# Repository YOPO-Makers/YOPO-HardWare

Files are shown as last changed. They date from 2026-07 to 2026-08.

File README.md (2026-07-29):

# 无人机硬件清单

| 硬件名 | 数量 | 功能简介 |
|---|---:|---|
| 边缘计算机套件：Nvidia Orin NX | 1 | [查看详细介绍](#detail-orin-nx) |
| RGB-D 深度相机：RealSense D455 | 1 | [查看详细介绍](#detail-d455) |
| 飞控：NxtPX4 | 1 | [查看详细介绍](#detail-nxtpx4) |
| 电调：45A（当前使用，型号待补充） | 1 | [查看详细介绍](#detail-esc-45a) |
| 电机：OddityRC 2006 2150KV 四个装 | 1 | [查看详细介绍](#detail-motor) |
| 螺旋桨：GEMFAN D90s-3 四个装 | 1 | [查看详细介绍](#detail-propeller) |
| 电池：1400mAh 6S | 1 | [查看详细介绍](#detail-battery) |
| 电池防撞护垫 | 1 | [查看详细介绍](#detail-battery-protector) |
| 电池绑带：凯夫拉 20×280mm 防滑扎带 | 1 | [查看详细介绍](#detail-battery-strap) |
| 桨叶保护罩：OddityRC XI35 Pro | 1 | [查看详细介绍](#detail-prop-guard) |
| 接收器：瑞速 | 1 | [查看详细介绍](#detail-receiver) |
| 遥控器 | 1 | [查看详细介绍](#detail-transmitter) |
| 电源接口：XT60 E1-M | 1 | [查看详细介绍](#detail-xt60-em) |
| XT30 对（10 个装） | 1 | [查看详细介绍](#detail-xt30) |
| 计算机电源线：18 AWG 红色，1m 长 | 4 | [查看详细介绍](#detail-power-red) |
| 计算机电源线：18 AWG 黑色，1m 长 | 4 | [查看详细介绍](#detail-power-black) |
| 硅胶线：28 AWG 绿色，0.08平方，5m 长 | 1 | [查看详细介绍](#detail-wire-28awg-green) |
| 硅胶线：28 AWG 白色，0.08平方，5m 长 | 1 | [查看详细介绍](#detail-wire-28awg-white) |
| 硅胶线：28 AWG 红色，0.08平方，5m 长 | 1 | [查看详细介绍](#detail-wire-28awg-red) |
| 硅胶线：28 AWG 黑色，0.08平方，5m 长 | 1 | [查看详细介绍](#detail-wire-28awg-black) |
| 相机 Type-C 线 | 1 | [查看详细介绍](#detail-camera-cable) |
| Type-C 调试母座（机架下板安装位） | 1 | [查看详细介绍](#detail-debug-female) |
| Type-C 调试公头 | 1 | [查看详细介绍](#detail-debug-male) |
| DC-DC 降压模块，输出 12V 5A | 1 | [查看详细介绍](#detail-dcdc) |
| 铝合金支柱：M3×12mm | 7颗 | [查看详细介绍](#detail-standoff) |
| 内六角沉头螺丝M3×10mm | 7颗 | [查看详细介绍](#detail-screw) |
| 尼龙螺丝：M2×20mm，白色 | 4颗 | [查看详细介绍](#detail-nylon-screw-m2-20) |
| 尼龙螺母：M2，白色 | 8颗 | [查看详细介绍](#detail-nylon-nut-m2) |
| 内六角沉头螺丝：M3×20mm | 6颗 | [查看详细介绍](#detail-countersunk-m3-20) |
| 内六角沉头螺丝：M2.5×10mm | 2颗 | [查看详细介绍](#detail-countersunk-m2-5-10) |
| 内六角沉头螺丝：M2.5×7mm | 4颗 | [查看详细介绍](#detail-countersunk-m2-5-7) |
| 内六角平头螺丝：M4×8mm | 2颗 | [查看详细介绍](#detail-screw-m4-8) |
| 平头螺丝：M3×12mm | 2颗 | [查看详细介绍](#detail-flat-screw-m3-12) |
| 平头螺丝：M3×14mm | 1颗 | [查看详细介绍](#detail-flat-screw-m3-14) |
| 防松螺母：M3 | 2颗 | [查看详细介绍](#detail-locknut-m3) |
| 缓冲泡棉（用于电池，2m） | 1 | [查看详细介绍](#detail-foam) |
| 3M 背胶魔术贴：黑色，2cm 宽，3m 勾面 + 3m 毛面 | 1 | [查看详细介绍](#detail-velcro) |
| 尼龙扎带：白色，25cm，中粗，100条装 | 1 | [查看详细介绍](#detail-zip-tie) |
| 固态电容：680µF（更紧凑） | 1 | [查看详细介绍](#detail-capacitor) |
| 热缩管：黑色，圆直径 4mm，按 2m 散卖 | 1 | [查看详细介绍](#detail-heatshrink-4mm) |
| 热缩管：黑色，圆直径 2mm，按 2m 散卖 | 1 | [查看详细介绍](#detail-heatshrink-2mm) |
| 热缩管：黑色，圆直径 25mm | 1 | [查看详细介绍](#detail-heatshrink-25mm) |
| 3K 东丽碳纤维板定制加工 | 1 | [查看详细介绍](#detail-carbon-fiber) |
| PETG 3D 打印定制件 | 6 | [查看详细介绍](#detail-petg-print) |
| BB 响 | 1 | [查看详细介绍](#detail-buzzer) |

## 硬件详细介绍

### 边缘计算机套件：Nvidia Orin NX

**具体型号：**

Allspark 2-Orin NX 16G+128G SSD+wifi版本 100TOPS

**功能简介：**

Nvidia Orin NX 是无人机上的机载边缘计算平台。

**参考图片：**

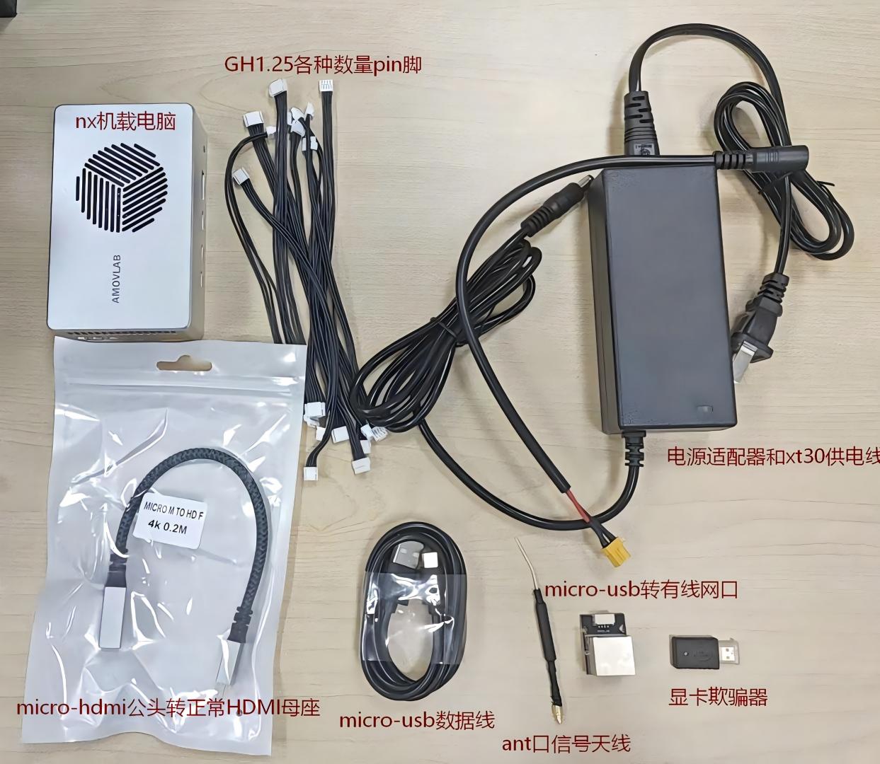
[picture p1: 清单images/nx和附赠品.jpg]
Nvidia Orin NX 及附赠品


**淘宝购买链接：**

[点击查看机载电脑商品（SKU：5396774401953）](https://item.taobao.com/item.htm?id=705748339987&skuId=5396774401953)

[返回硬件清单](#hardware-list)

### RGB-D 深度相机：RealSense D455

**功能简介：** 用于采集彩色图像和深度信息，为目标识别、测距、避障和定位提供视觉数据。

**参考图片：**

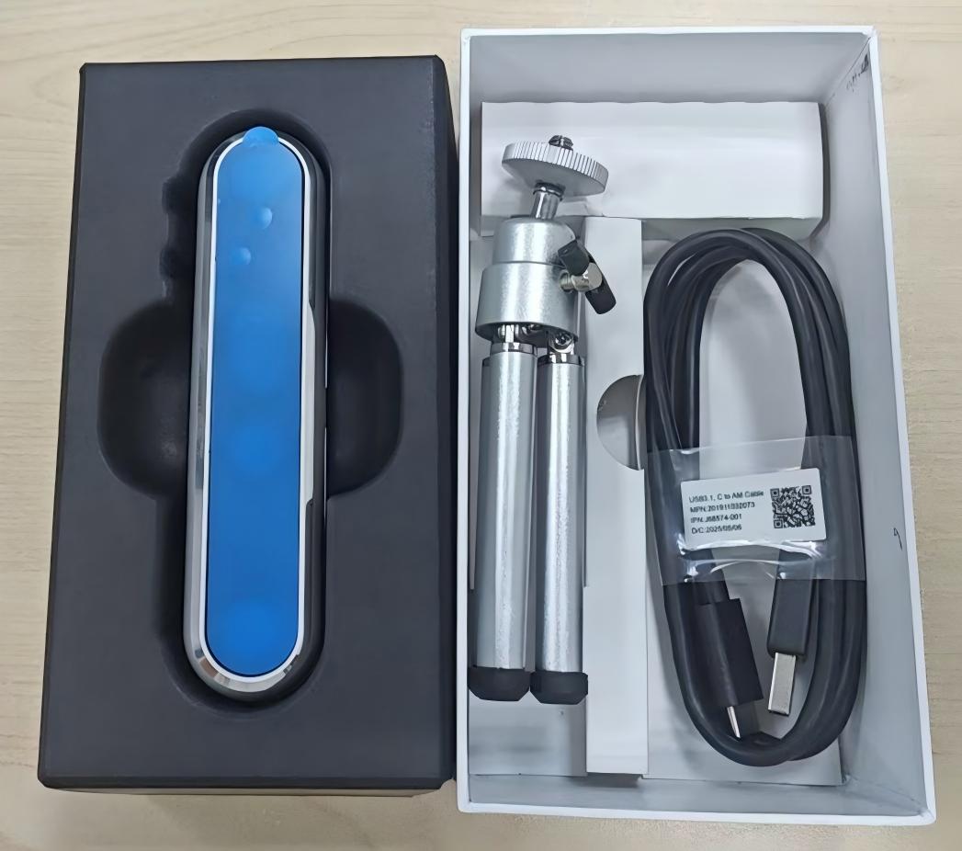
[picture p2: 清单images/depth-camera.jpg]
深度相机 示例图片


**淘宝购买链接：**

[点击查看深度相机商品（SKU：4457168412136）](https://item.taobao.com/item.htm?id=559722720199&skuId=4457168412136)

[返回硬件清单](#hardware-list)

### 飞控：NxtPX4

**功能简介：** 负责姿态估计、飞行控制、电机输出以及与遥控器、接收器和机载计算机的通信。

**淘宝购买链接：**

[点击查看飞控商品（SKU：6048678263114）](https://item.taobao.com/item.htm?id=955672079963&skuId=6048678263114)

**参考图片：**

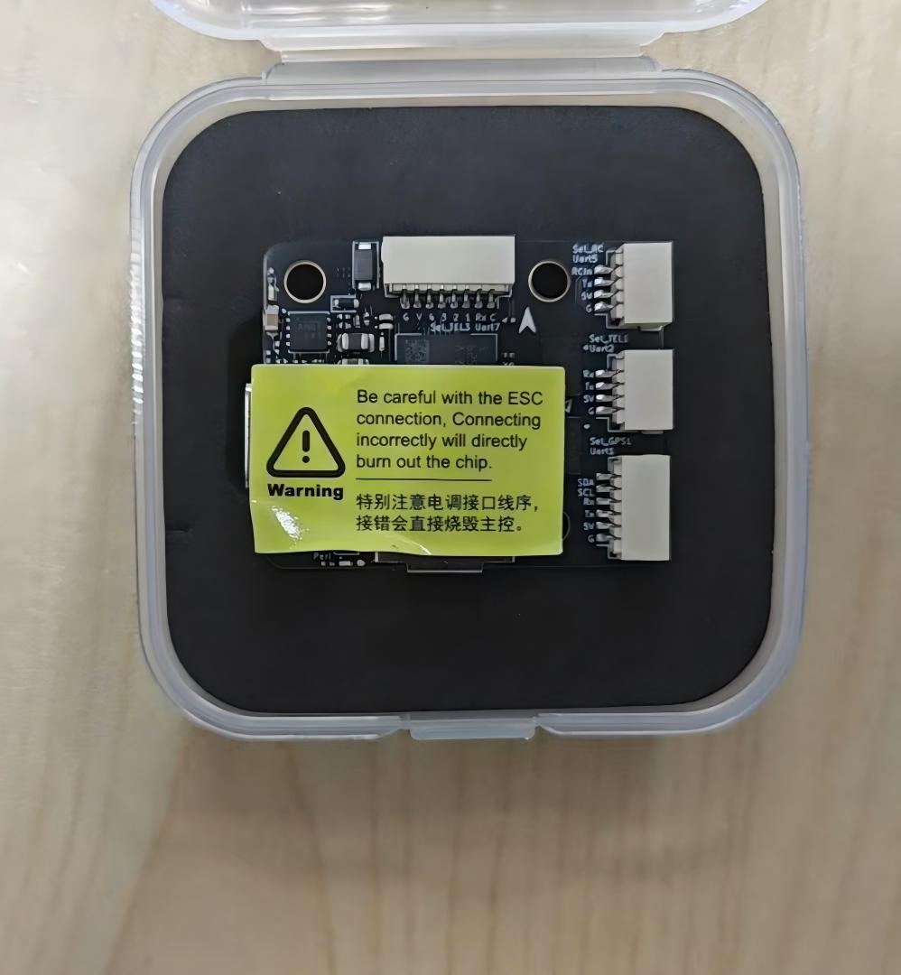
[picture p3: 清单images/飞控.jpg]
飞控 NxtPX4


[返回硬件清单](#hardware-list)

### 电调：45A（当前使用，型号待补充）

**功能简介：** 将 6S 电池的直流电转换为三相驱动信号，控制四个无刷电机的转速和方向。

**状态：** 当前方案使用尺寸匹配的 45A 电调，具体品牌、型号和淘宝购买链接待补充。

**参考图片：**

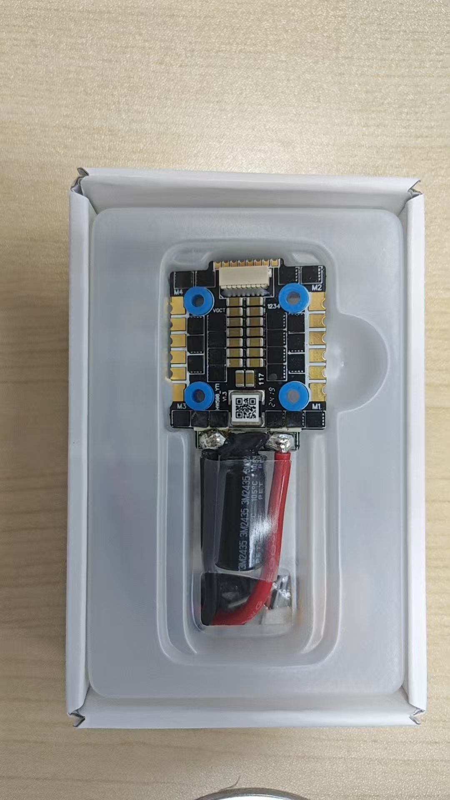
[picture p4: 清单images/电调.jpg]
45A 电调


[返回硬件清单](#hardware-list)

### 电机：OddityRC 2006 2150KV 四个装

**功能简介：** 为螺旋桨提供旋转动力，是无人机动力系统的核心执行部件；本款 2006 2150KV 电机适配三孔螺旋桨安装方式。

**参考图片：**

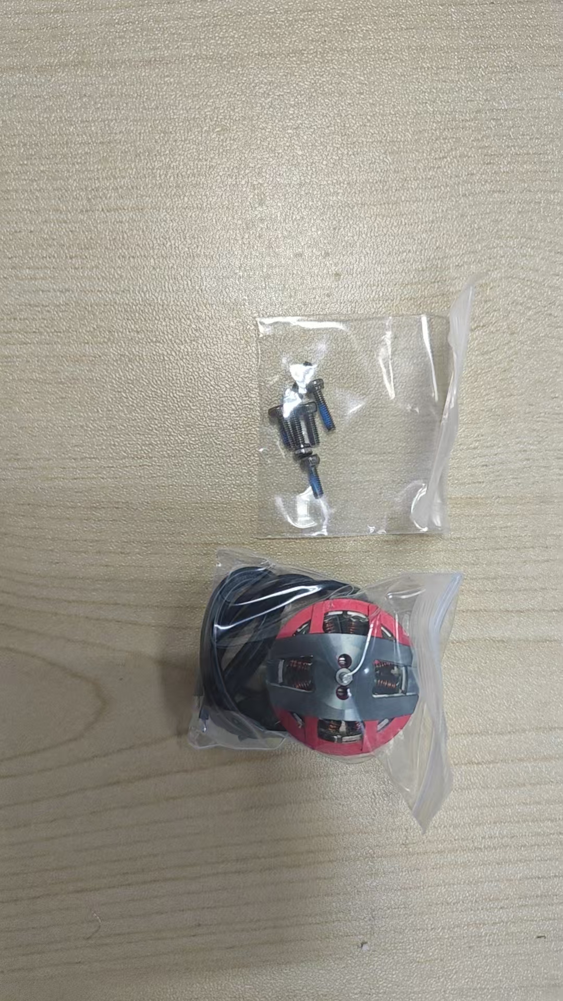
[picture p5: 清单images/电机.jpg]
无刷电机


**历史购买链接：**

[查看原 OddityRC 2006 电机商品（已售罄）](https://item.taobao.com/item.htm?id=793989229752&sku_properties=1627207%3A32402027293)

> 该商品已经卖完，此链接仅用于记录当初购买的型号，不代表当前可购买。

[返回硬件清单](#hardware-list)

### 螺旋桨：GEMFAN D90s-3 四个装

**功能简介：** 将电机的旋转动力转换为升力和推力，是无人机产生飞行动力的部件。

**参考图片：**

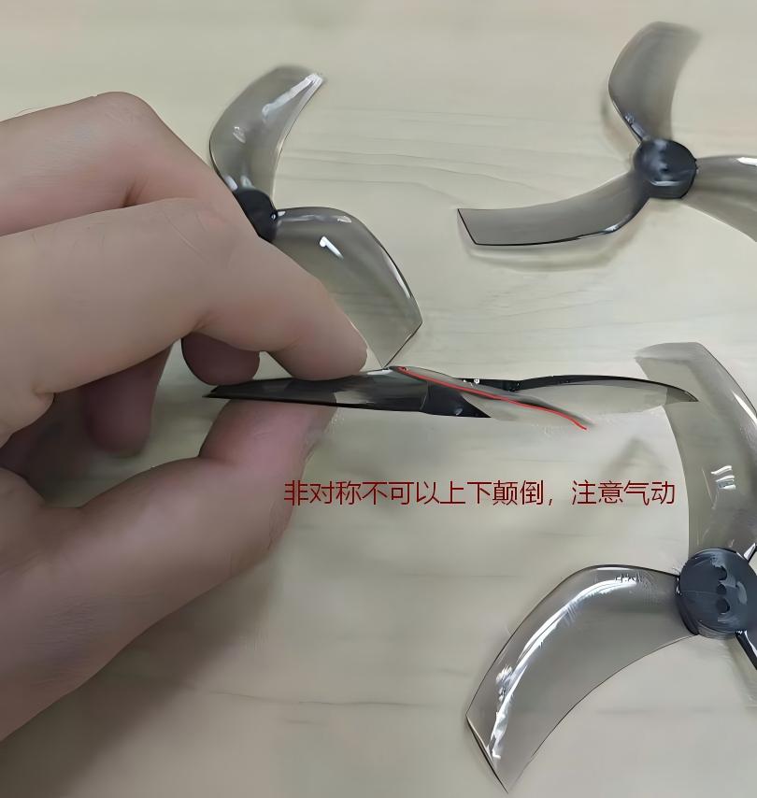
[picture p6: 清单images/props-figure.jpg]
三孔螺旋桨示意图


**购买链接：**

[点击查看三孔螺旋桨商品（SKU：5675481147990）](https://item.taobao.com/item.htm?id=811737228893&skuId=5675481147990)

> 本电机为中间光轴、两侧带安装孔，因此选用三孔螺旋桨；如果电机只有中间单轴、没有两侧安装孔，应改用单孔螺旋桨。

[返回硬件清单](#hardware-list)

### 电池：1400mAh 6S

**功能简介：** 为电机、电调和机载电子设备提供 6S 直流电源，是无人机的主要动力能源。

**参考图片：**

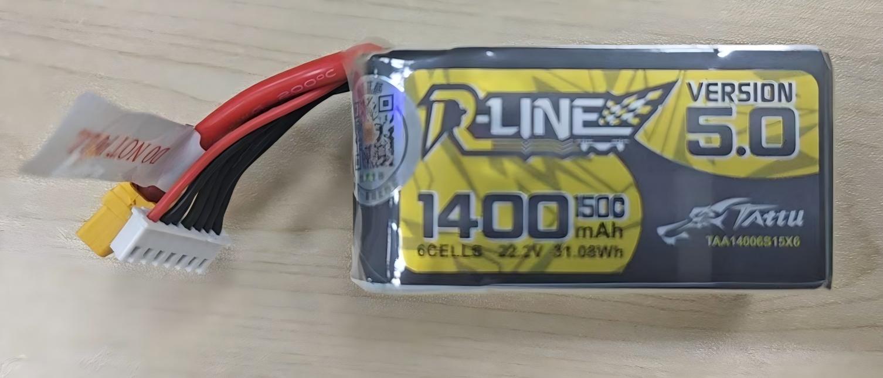
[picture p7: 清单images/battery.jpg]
1400mAh 6S 电池


**淘宝购买链接：**

[点击查看淘宝商品（SKU：5449796720472）](https://item.taobao.com/item.htm?id=677691756050&skuId=5449796720472)

**参考购买价：** 166.50 元

[返回硬件清单](#hardware-list)

### 电池防撞护垫

**功能简介：** 用于缓冲电池与机架或周边结构的碰撞，减少电池外壳磨损和飞行振动。

**参考图片：**

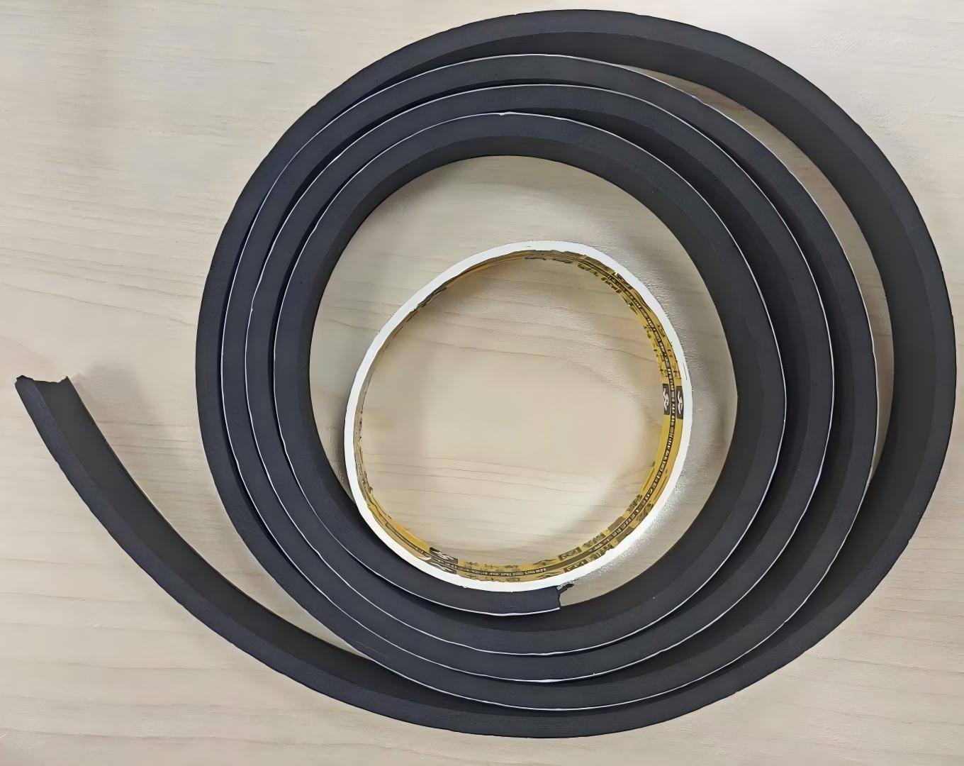
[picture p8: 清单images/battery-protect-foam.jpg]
电池防撞护垫


**淘宝购买链接：**

[点击查看电池防撞商品（SKU：6010611489926）](https://item.taobao.com/item.htm?id=1008514063717&skuId=6010611489926)

[返回硬件清单](#hardware-list)

### 电池绑带：凯夫拉 20×280mm 防滑扎带

**功能简介：** 用于固定 5 寸及 7 寸穿越机电池，防止电池在飞行过程中移动或脱落。

**规格：** 凯夫拉材质，20×280mm，防滑款，数量 4。

**淘宝购买链接：**

[点击查看商品（商品 ID：752606680898）](https://item.taobao.com/item.htm?id=752606680898)

**参考图片：**

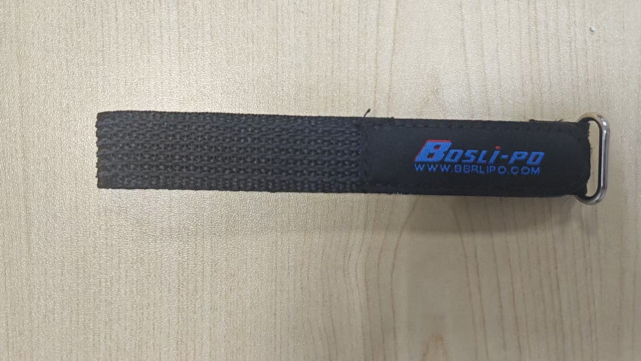
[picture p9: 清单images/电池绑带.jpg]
电池绑带


[返回硬件清单](#hardware-list)

### 桨叶保护罩：OddityRC XI35 Pro

**功能简介：** 用于隔离螺旋桨与外部障碍物，降低碰撞时桨叶和人员受伤的风险。

**参考图片：**

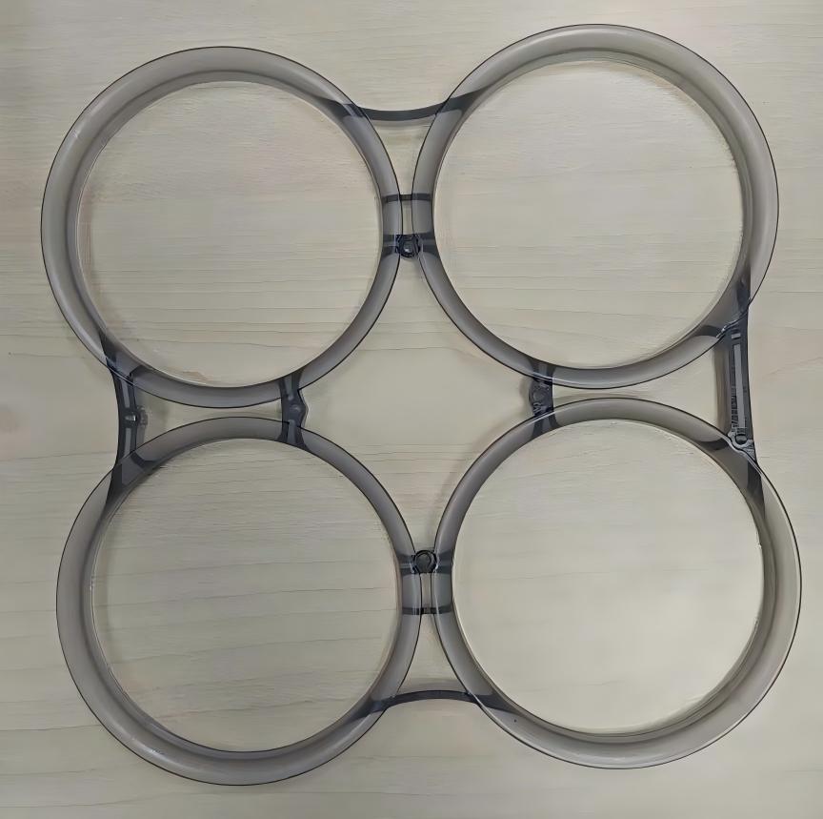
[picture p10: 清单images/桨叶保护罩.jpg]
桨叶保护罩


**淘宝购买链接：**

[点击查看涵道保护圈商品（SKU：5815214173777）](https://item.taobao.com/item.htm?id=930567172186&skuId=5815214173777)

[返回硬件清单](#hardware-list)

### 接收器：瑞速

**功能简介：** 接收遥控器发出的控制指令，并传递给飞控执行油门、姿态和模式控制。

**参考图片：**

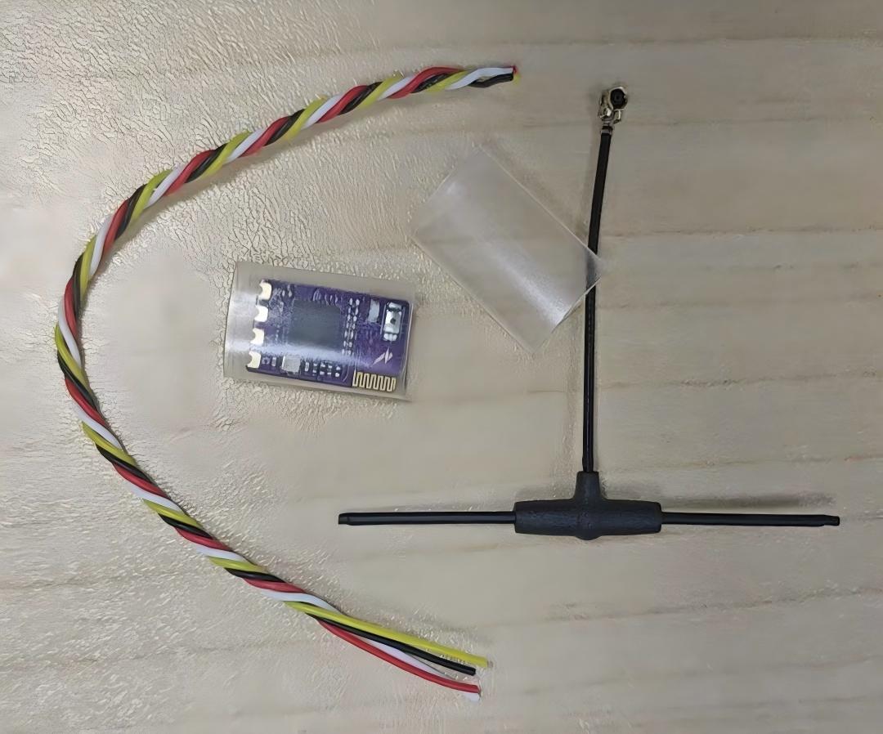
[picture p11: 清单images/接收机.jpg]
接收机


**淘宝购买链接：**

[点击查看接收机商品（SKU：6059615692701）](https://item.taobao.com/item.htm?id=1039148819082&skuId=6059615692701)

[返回硬件清单](#hardware-list)

### 遥控器

**功能简介：** 用于向接收器发送飞行控制、模式切换和安全解锁指令。

**参考图片：**

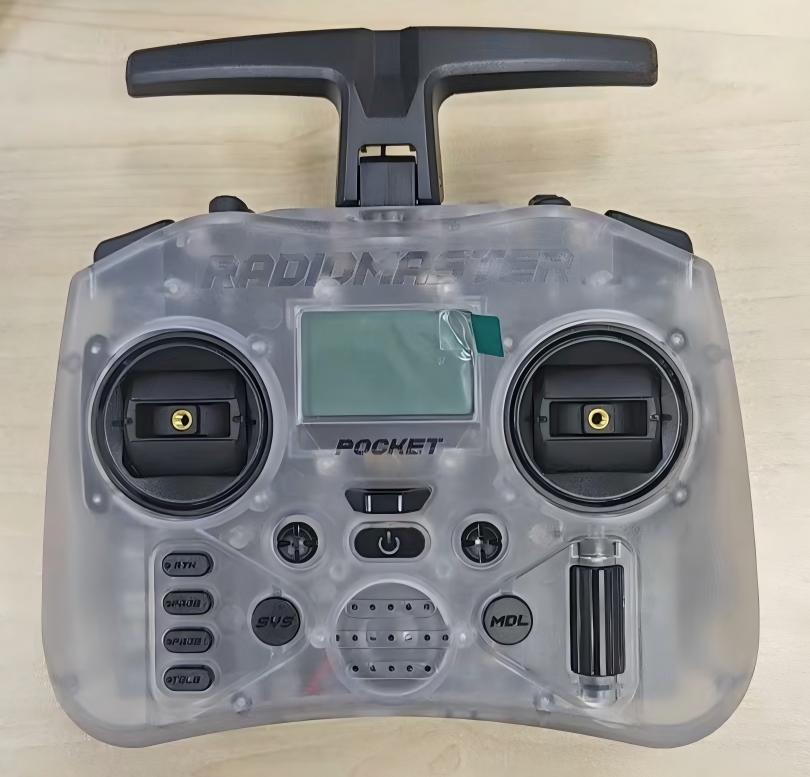
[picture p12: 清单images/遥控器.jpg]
遥控器


**淘宝购买链接：**

[点击查看遥控器商品（SKU：5690791865430）](https://item.taobao.com/item.htm?id=789612406107&skuId=5690791865430)

[返回硬件清单](#hardware-list)

### 电源接口：XT60 E1-M

**功能简介：** 提供电池与无人机电源系统之间的大电流可插拔连接。

**参考图片：**

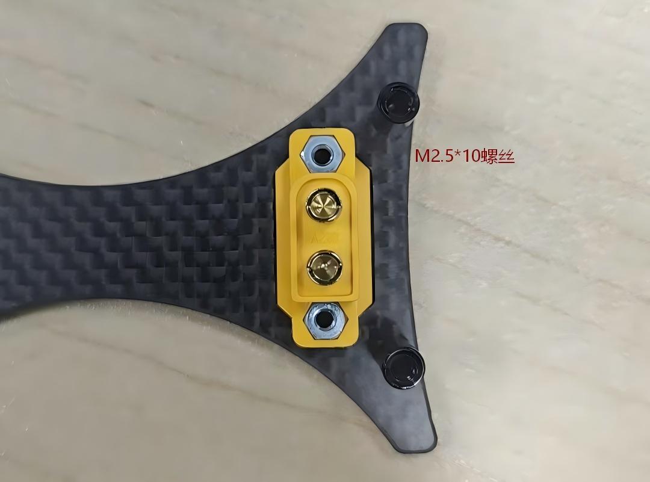
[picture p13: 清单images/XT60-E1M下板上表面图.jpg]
XT60 E1-M 在机架下板上的安装位置


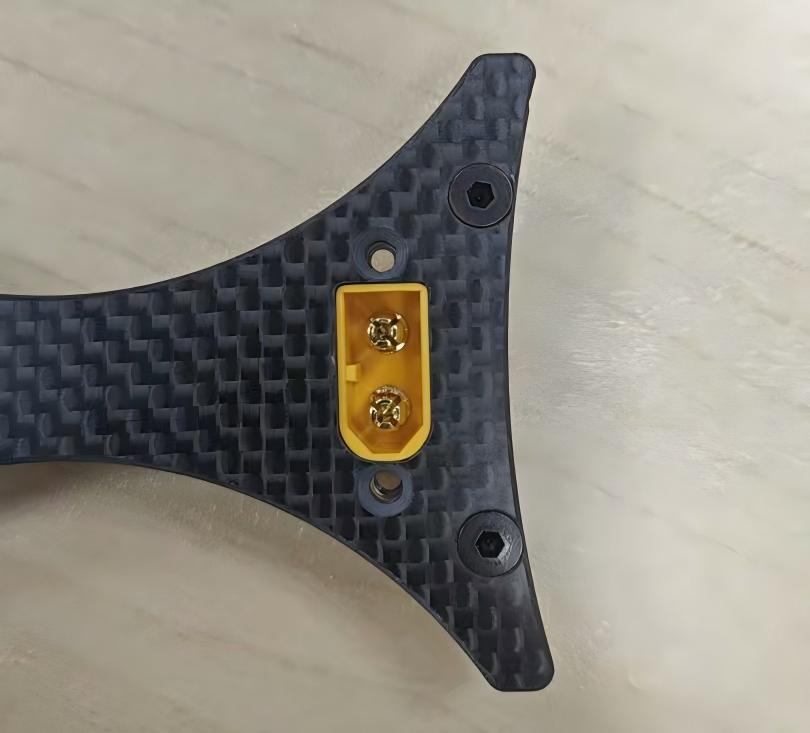
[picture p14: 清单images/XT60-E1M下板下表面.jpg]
XT60 E1-M 机架下板背面


**淘宝购买链接：**

[点击查看 XT60 E1-M 公头商品（SKU：4662287222244）](https://detail.tmall.com/item.htm?id=631049982867&skuId=4662287222244)

> 机架下板为该 XT60E1-M 预留了安装位；商品不含固定用 M2 螺丝，需另行准备。

[返回硬件清单](#hardware-list)

### XT30 对（10 个装）

**功能简介：** 用于较小电流的辅助电源连接，例如风扇、灯光或小型模块。

**淘宝购买链接：**

[点击查看 XT30 公母对商品（SKU：5808932883156）](https://item.taobao.com/item.htm?id=849568874754&skuId=5808932883156)

> 该 XT30 公母对用于机载电脑供电。

**参考图片：**

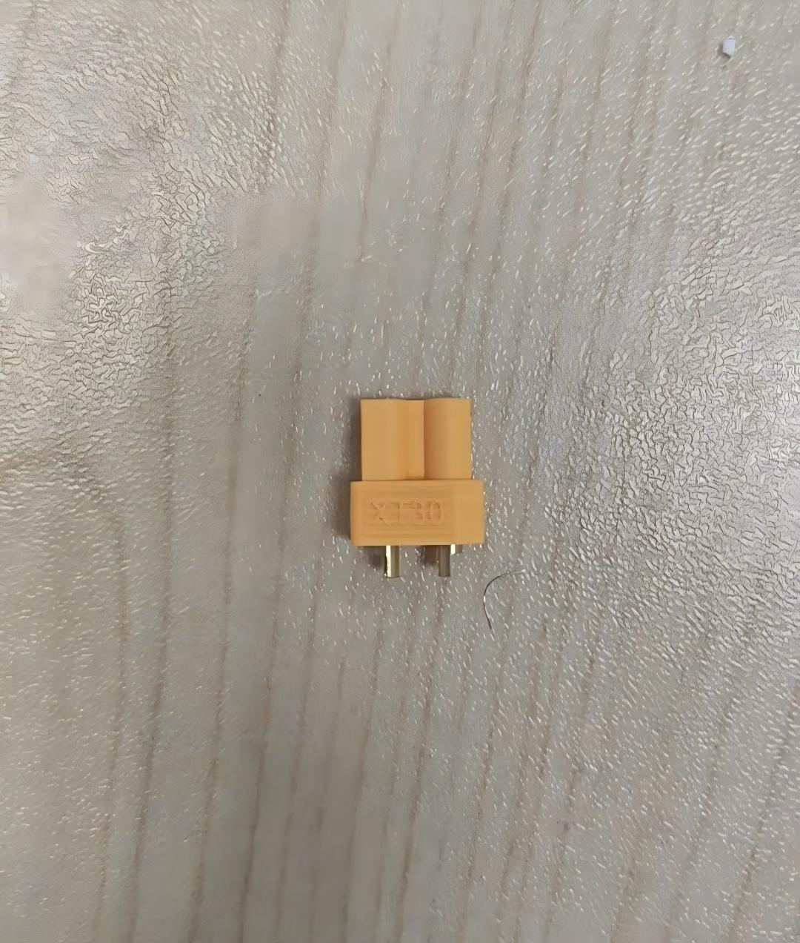
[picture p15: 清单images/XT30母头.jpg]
XT30 母头


[返回硬件清单](#hardware-list)

### 计算机电源线：18 AWG 红色，1m 长

**功能简介：** 作为计算机或机载设备电源连接中的正极线，提供较大电流承载能力。

**淘宝购买链接：**

[点击查看红色 18 AWG 硅胶线商品（SKU：4599704214171）](https://detail.tmall.com/item.htm?id=624893192274&skuId=4599704214171)

**参考图片：**

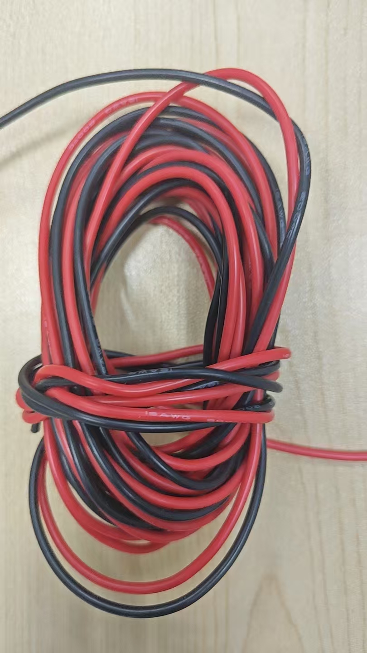
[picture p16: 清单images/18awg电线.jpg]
18 AWG 电线


[返回硬件清单](#hardware-list)

### 计算机电源线：18 AWG 黑色，1m 长

**功能简介：** 作为计算机或机载设备电源连接中的负极/地线，与红色电源线配合使用。

**淘宝购买链接：**

[点击查看黑色 18 AWG 硅胶线商品（SKU：4599704214172）](https://detail.tmall.com/item.htm?id=624893192274&skuId=4599704214172)

> 该 18 AWG 线用于 XT30 接线，配套使用 4mm 热缩管。

**参考图片：**

18 AWG 电线

[返回硬件清单](#hardware-list)

### 硅胶线：28 AWG 绿色，0.08平方，5m 长

**功能简介：** 用于低电流信号、控制和辅助连接线路。

**规格：** 28 AWG，0.08平方，绿色，5m。

**淘宝购买链接：**

[点击查看商品（商品 ID：736162720327）](https://item.taobao.com/item.htm?id=736162720327)

[返回硬件清单](#hardware-list)

### 硅胶线：28 AWG 白色，0.08平方，5m 长

**功能简介：** 用于低电流信号、控制和辅助连接线路。

**规格：** 28 AWG，0.08平方，白色，5m。

**淘宝购买链接：**

[点击查看商品（商品 ID：736162720327）](https://item.taobao.com/item.htm?id=736162720327)

[返回硬件清单](#hardware-list)

### 硅胶线：28 AWG 红色，0.08平方，5m 长

**功能简介：** 用于低电流信号、控制和辅助连接线路；红色可作为正极或电源标识线。

**规格：** 28 AWG，0.08平方，红色，5m。

**淘宝购买链接：**

[点击查看商品（商品 ID：736162720327）](https://item.taobao.com/item.htm?id=736162720327)

[返回硬件清单](#hardware-list)

### 硅胶线：28 AWG 黑色，0.08平方，5m 长

**功能简介：** 用于低电流信号、控制和辅助连接线路；黑色可作为负极或地线标识线。

**规格：** 28 AWG，0.08平方，黑色，5m。

**淘宝购买链接：**

[点击查看商品（商品 ID：736162720327）](https://item.taobao.com/item.htm?id=736162720327)

[返回硬件清单](#hardware-list)

### 相机 Type-C 线

**功能简介：** 用于连接 RealSense D455 等相机与边缘计算机，传输图像、深度数据并提供接口供电。

**购买说明：**

>  yopo提供的相机 Type-C 链接不适配当前设备，不要购买，也不作为本清单的有效购买链接。应使用与 RealSense D455 接口匹配的正确线材。

**参考图片：**

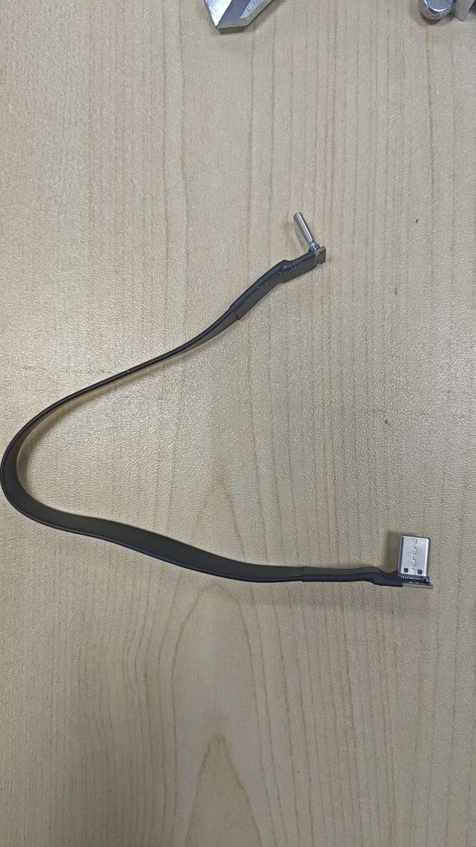
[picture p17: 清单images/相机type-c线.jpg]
相机 Type-C 线


[返回硬件清单](#hardware-list)

### Type-C 调试母座（机架下板安装位）

**功能简介：** 作为可插拔的调试和烧录连接端，用于临时接入飞控或其他控制板。这个东西和公头连起来以后，公头插飞控，母座放底板上，方便调试，本质是一个转接功能。母座需要导圆角。

**参考图片：**

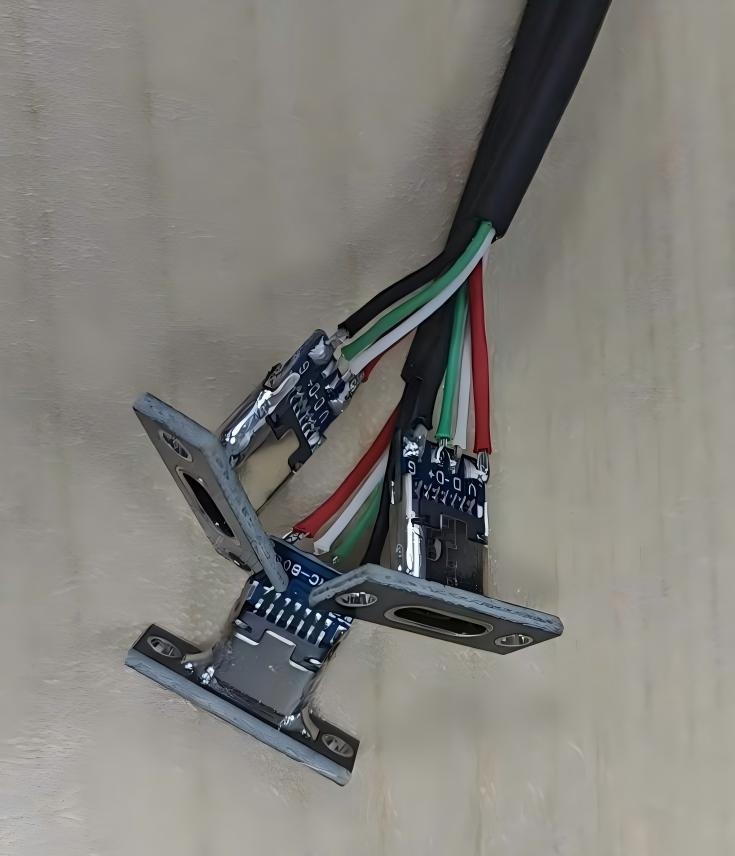
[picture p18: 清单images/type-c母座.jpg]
Type-C 调试母座


**淘宝购买链接：**

[点击查看 Type-C 调试母座商品（SKU：5102665524058）](https://item.taobao.com/item.htm?id=739748700093&skuId=5102665524058)

> 机架下板为该 Type-C 调试母座预留了专门安装位置。

[返回硬件清单](#hardware-list)

### Type-C 调试公头

**功能简介：** 与母头配合，为调试线、烧录器或外部测试设备提供插接端。直接用废弃数据线加上母座，所以这个type-c公头已经不重要了。

**参考图片：**

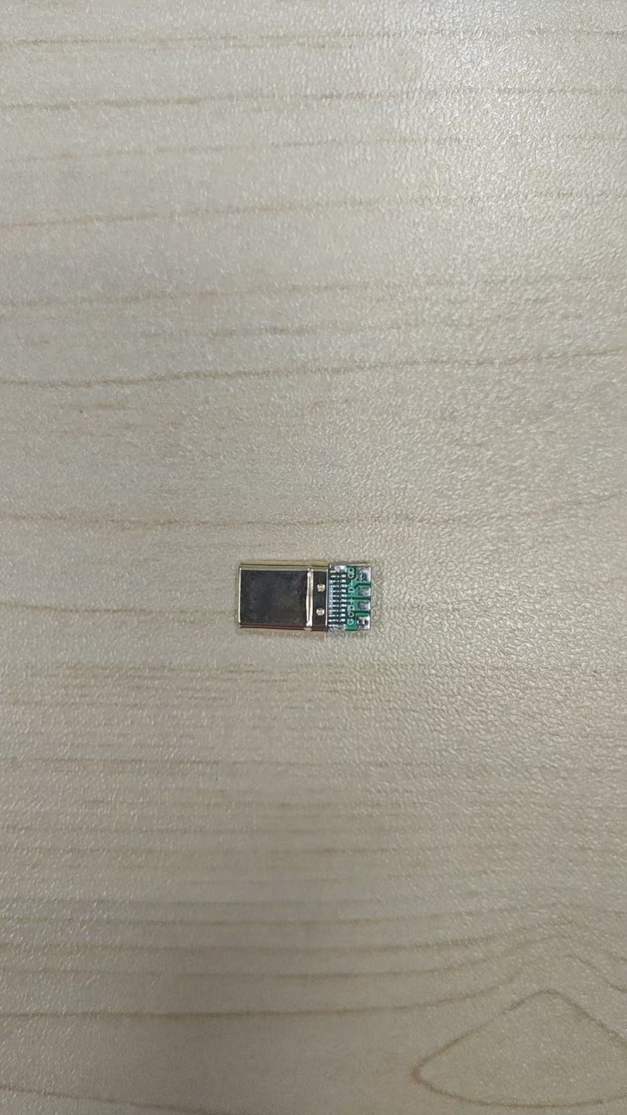
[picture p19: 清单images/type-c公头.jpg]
Type-C 调试公头


**淘宝购买链接：**

[点击查看 Type-C 调试公头商品（SKU：5077068792858）](https://item.taobao.com/item.htm?id=734551790057&skuId=5077068792858)

[返回硬件清单](#hardware-list)

### DC-DC 降压模块，输出 12V 5A

**功能简介：** 将电池或主电源的较高电压转换为稳定的 12V 电源，为机载计算机、相机或其他设备供电。

**参考图片：**

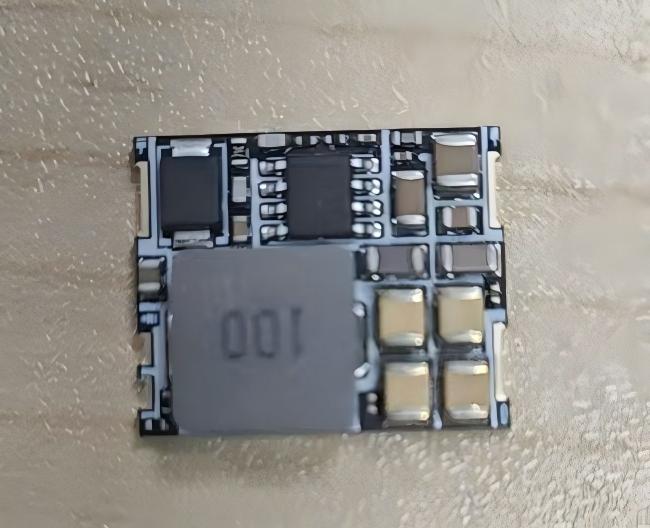
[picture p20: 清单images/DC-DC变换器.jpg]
DC-DC 12V 降压模块


**淘宝购买链接：**

[点击查看 DC-DC 降压模块商品（SKU：6264144190644）](https://item.taobao.com/item.htm?id=677122068881&skuId=6264144190644)

> 用于将 6S 电池电压转换为稳定的 12V，为机载电脑供电。

[返回硬件清单](#hardware-list)

### 铝合金支柱：M3×12mm

**功能简介：** 用于连接上层碳板。

**淘宝购买链接：**

[点击查看 M3×12mm 铝合金支柱商品（SKU：5379794304693）](https://item.taobao.com/item.htm?id=788489376891&skuId=5379794304693)

**参考图片：**

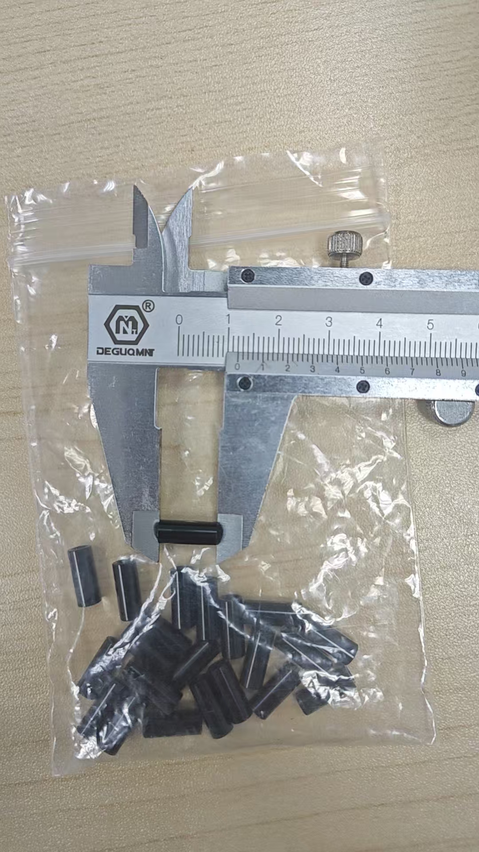
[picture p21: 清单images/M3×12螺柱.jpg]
M3×12 螺柱


[返回硬件清单](#hardware-list)

### 内六角沉头螺丝M3×10mm

**功能简介：** 用于机架、支柱和设备安装，沉头结构可减少螺丝头突出造成的干涉。

**参考图片：**

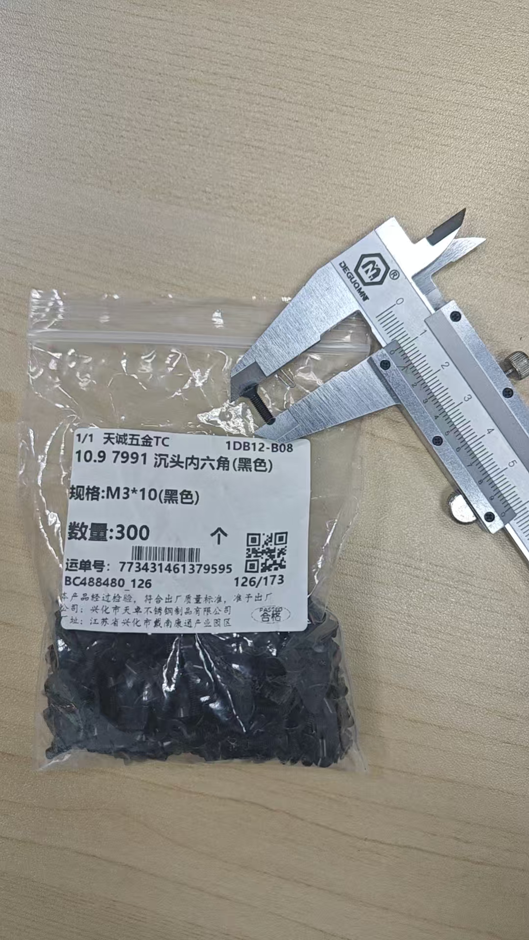
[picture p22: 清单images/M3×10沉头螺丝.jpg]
M3×10 沉头螺丝


[返回硬件清单](#hardware-list)

### 尼龙螺丝：M2×20mm，白色

**功能简介：** 用于轻量化、绝缘的设备安装和结构固定。

**规格：** 白色尼龙螺丝，M2×20mm，30颗装。

**淘宝购买链接：**

[点击查看商品（商品 ID：43496648279）](https://item.taobao.com/item.htm?id=43496648279)

**参考图片：**

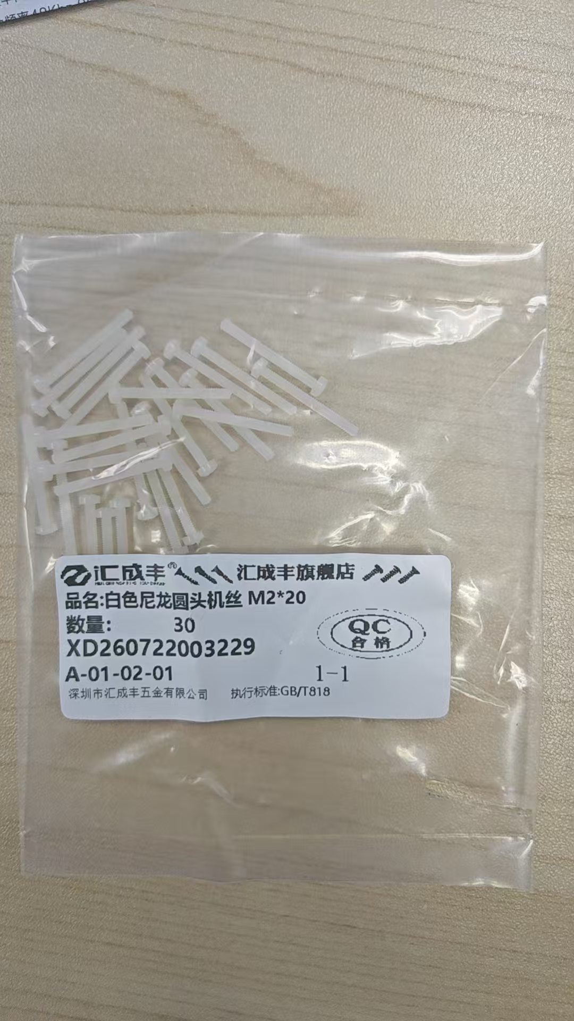
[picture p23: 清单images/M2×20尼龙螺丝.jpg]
M2×20 尼龙螺丝


[返回硬件清单](#hardware-list)

### 尼龙螺母：M2，白色

**功能简介：** 与 M2 螺丝配合使用，用于绝缘安装和轻量化固定。

**规格：** 白色尼龙六角螺母，M2，50颗装。

**淘宝购买链接：**

[点击查看商品（商品 ID：38154327797）](https://item.taobao.com/item.htm?id=38154327797)

**参考图片：**

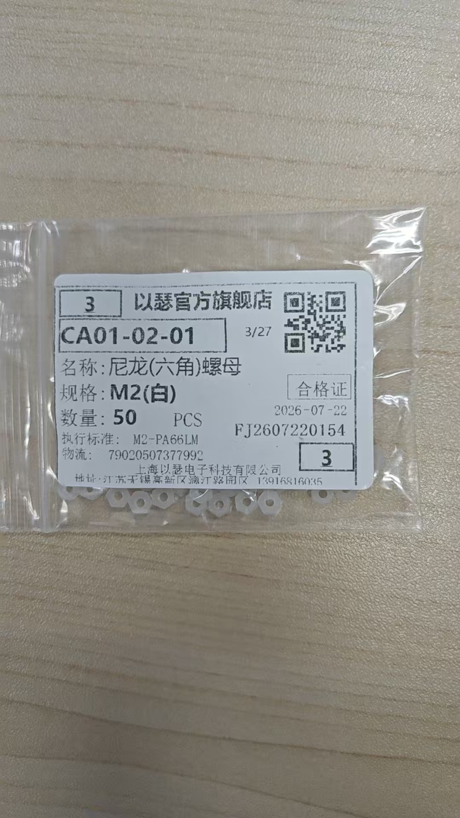
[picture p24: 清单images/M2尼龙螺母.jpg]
M2 尼龙螺母


[返回硬件清单](#hardware-list)

### 内六角沉头螺丝：M3×20mm

**功能简介：** 用于飞行器机架、支柱和设备安装的沉头固定，减少螺丝头对周边部件的干涉。

**规格：** M3×20mm，100只装。

**淘宝购买链接：**

[点击查看商品（商品 ID：593668961775）](https://item.taobao.com/item.htm?id=593668961775)

**参考图片：**

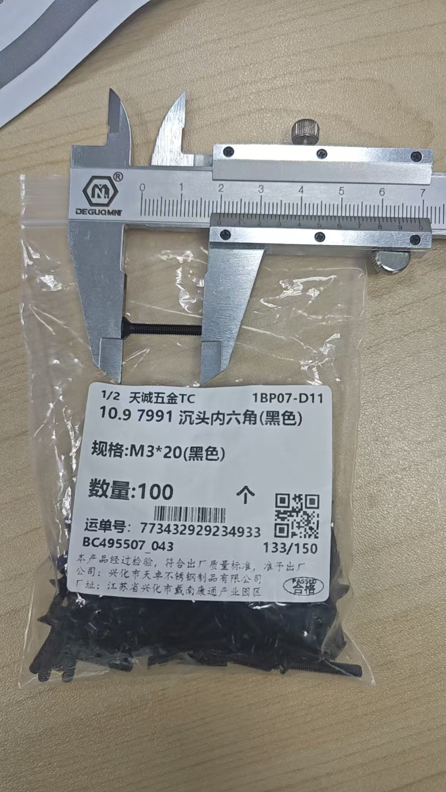
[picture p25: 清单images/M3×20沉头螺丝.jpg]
M3×20 沉头螺丝


[返回硬件清单](#hardware-list)

### 内六角沉头螺丝：M2.5×10mm

**功能简介：** 用于小型设备、支架和电路板附件的沉头固定。

**规格：** M2.5×10mm，100只装。

**淘宝购买链接：**

[点击查看商品（商品 ID：593668961775）](https://item.taobao.com/item.htm?id=593668961775)

**参考图片：**

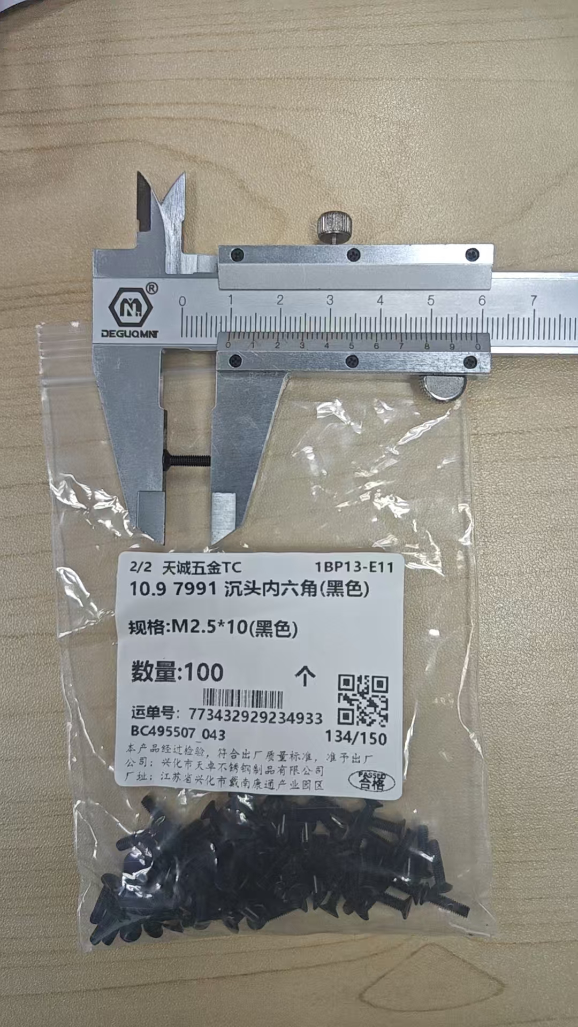
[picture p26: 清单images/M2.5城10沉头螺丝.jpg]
M2.5×10 沉头螺丝


[返回硬件清单](#hardware-list)

### 内六角沉头螺丝：M2.5×7mm

**功能简介：** 用于较薄结构件或小型安装位的沉头固定，长度比 M2.5×10mm 更短，可减少穿透或顶到内部结构的风险。

**规格：** M2.5×7mm，数量 4 颗。

[返回硬件清单](#hardware-list)

### 内六角平头螺丝：M4×8mm

**功能简介：** 用于 M4 孔位的结构固定，平头结构能减少螺丝头突出带来的干涉。

**参考图片：**

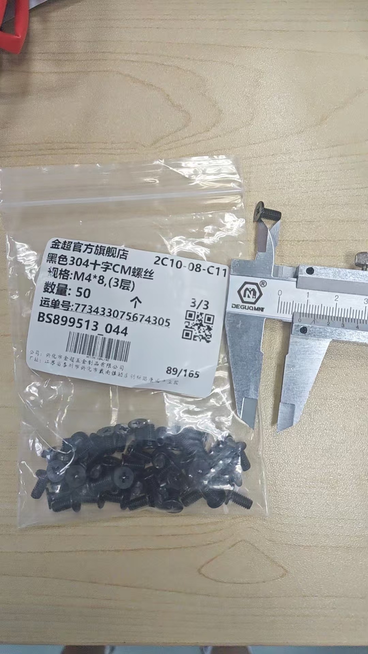
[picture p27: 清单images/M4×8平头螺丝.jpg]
M4×8 平头螺丝


[返回硬件清单](#hardware-list)

### 平头螺丝：M3×12mm

**功能简介：** 用于 M3 孔位的结构连接，可与支柱、防松螺母或其他 M3 固定件配合使用。

**参考图片：**

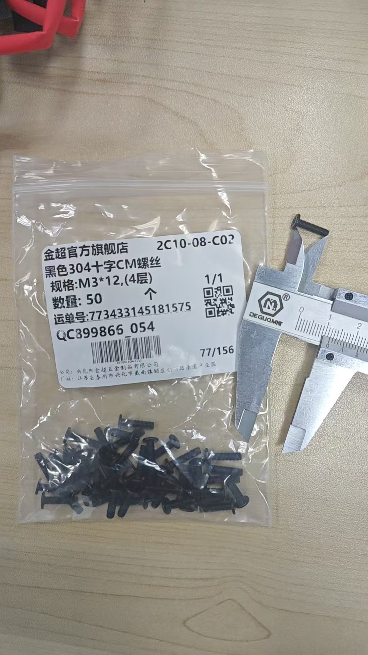
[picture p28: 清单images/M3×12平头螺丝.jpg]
M3×12 平头螺丝


[返回硬件清单](#hardware-list)

### 平头螺丝：M3×14mm

**功能简介：** 用于唯一的一个仅链接上板和桨叶保护圈的螺丝。

**参考图片：**

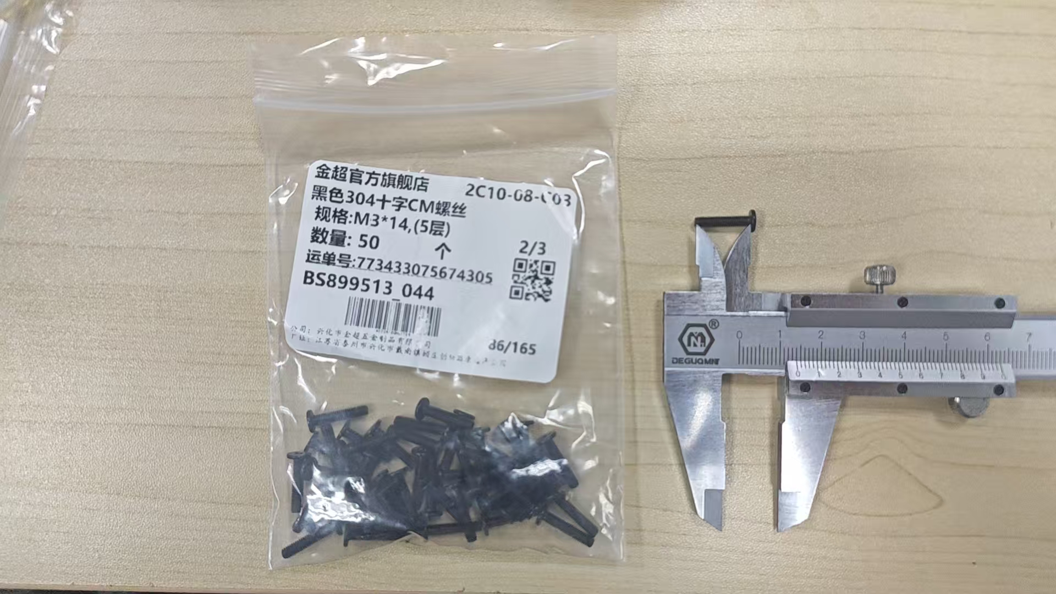
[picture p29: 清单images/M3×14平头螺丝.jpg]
M3×14 平头螺丝


[返回硬件清单](#hardware-list)

### 防松螺母：M3

**功能简介：** 与 M3 螺丝配合，用于振动较大的位置，降低飞行过程中螺丝松动的概率。

**参考图片：**

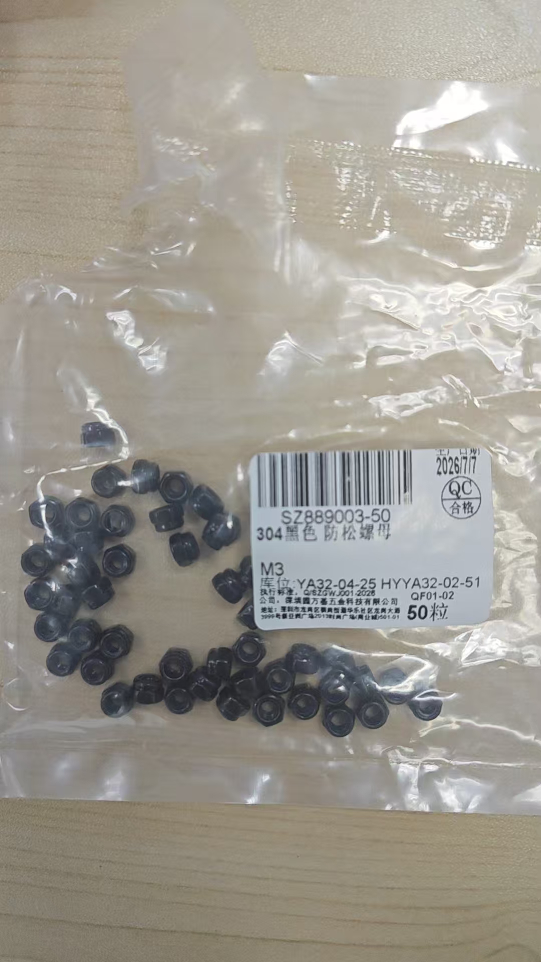
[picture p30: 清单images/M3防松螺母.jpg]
M3 防松螺母


[返回硬件清单](#hardware-list)

### 缓冲泡棉（用于电池，2m）

**功能简介：** 用于电池与碳板之间的缓冲、防滑和减振，降低电池外壳磨损。

[返回硬件清单](#hardware-list)

### 3M 背胶魔术贴：黑色，2cm 宽，3m 勾面 + 3m 毛面

**功能简介：** 用于可拆卸固定电池、电调及其他机载设备，方便后续维护和调整。

**规格：** 黑色，宽 2cm，3m 勾面加 3m 毛面，数量 1 套。

**淘宝购买链接：**

[点击查看商品（商品 ID：911291973150）](https://item.taobao.com/item.htm?id=911291973150)

**参考图片：**

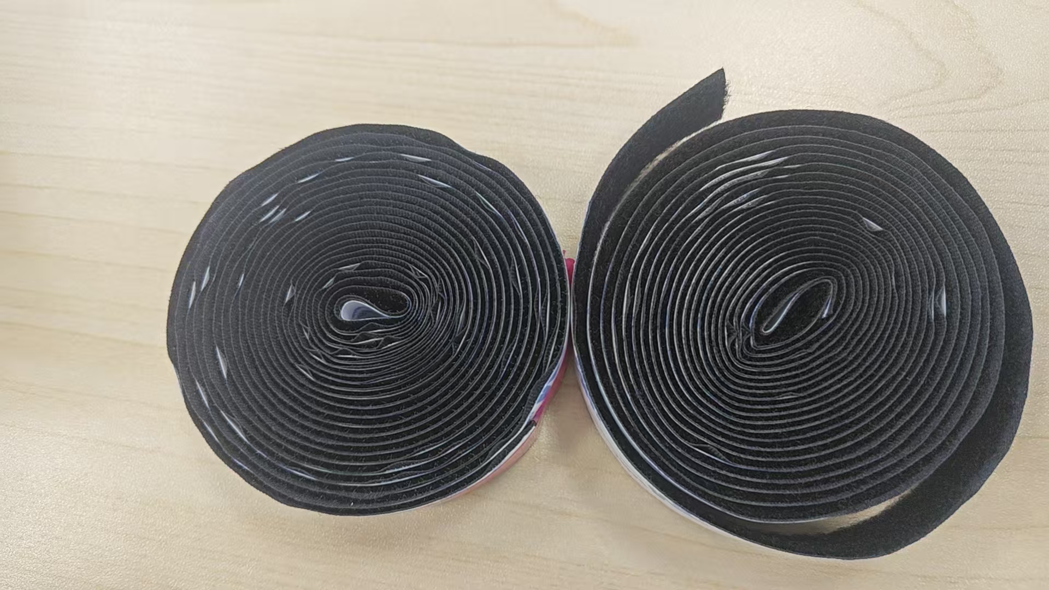
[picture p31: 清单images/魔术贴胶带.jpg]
魔术贴胶带


[返回硬件清单](#hardware-list)

### 尼龙扎带：白色，25cm，中粗，100条装

**功能简介：** 用于固定电调、电源线、信号线和其他机架附件，也可作为双面胶固定后的辅助防脱落措施。

**规格：** 白色，25cm，中粗，100条装，数量 1 包。

**淘宝购买链接：**

[点击查看商品（商品 ID：552436283189）](https://item.taobao.com/item.htm?id=552436283189)

**参考图片：**

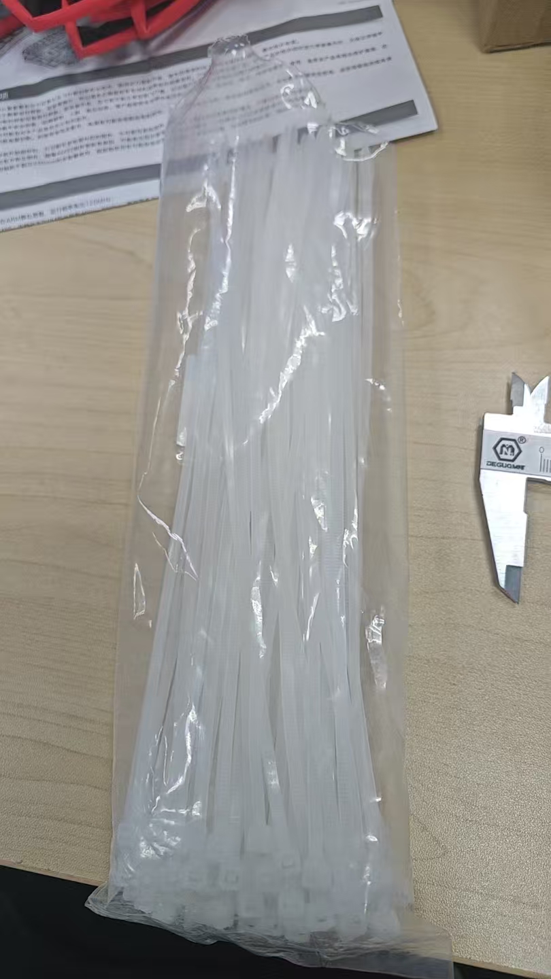
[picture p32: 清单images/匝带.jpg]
尼龙扎带


[返回硬件清单](#hardware-list)

### 固态电容：680µF（更紧凑）

**功能简介：** 用于吸收电源瞬态波动和高频噪声，改善电调和飞控供电稳定性。

**淘宝购买链接：**

[点击查看固态电容商品（商品 ID：721200592831）](https://item.taobao.com/item.htm?id=721200592831)

> 用于电池侧稳压；目前安装空间较紧，需要结合机架布局确定固定方式。

**参考图片：**

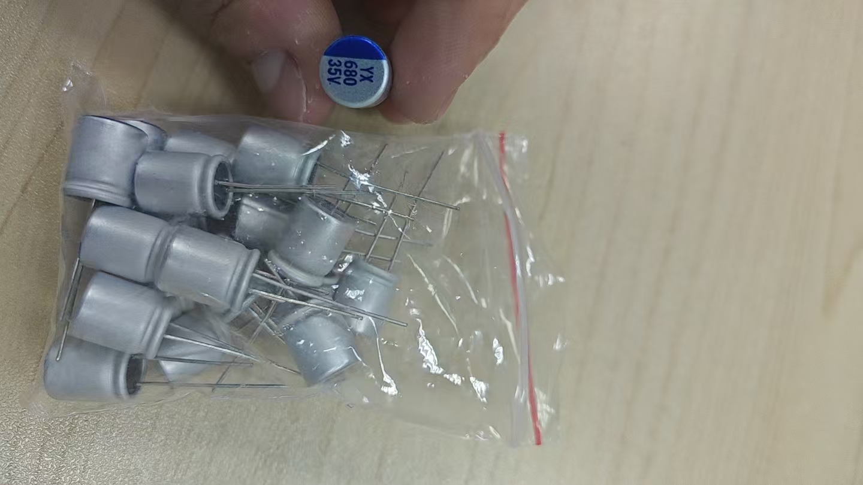
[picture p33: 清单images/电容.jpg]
固态电容


[返回硬件清单](#hardware-list)

### 热缩管：黑色，圆直径 4mm，按 2m 散卖

**功能简介：** 用于电源线、焊点和接插件的绝缘保护及防磨损处理。

**规格：** 黑色，圆直径 4mm，购买长度 2m。

**淘宝购买链接：**

[点击查看商品（商品 ID：631556426007）](https://item.taobao.com/item.htm?id=631556426007)

**参考图片：**

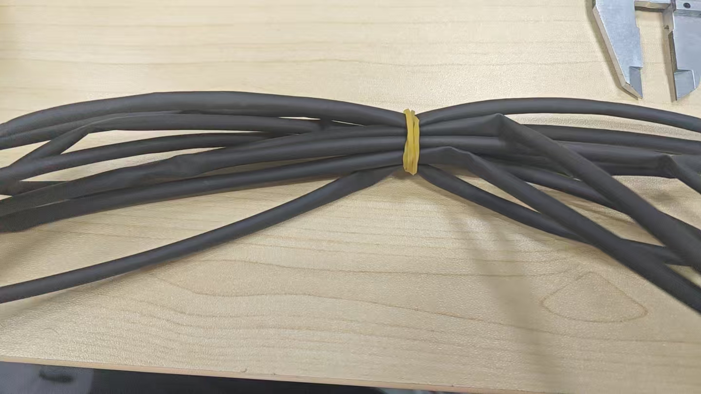
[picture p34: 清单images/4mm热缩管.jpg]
4mm 热缩管


[返回硬件清单](#hardware-list)

### 热缩管：黑色，圆直径 2mm，按 2m 散卖

**功能简介：** 用于较细电线、信号线和焊点的绝缘保护及束线处理。

**规格：** 黑色，圆直径 2mm，购买长度 2m。

**淘宝购买链接：**

[点击查看商品（商品 ID：631556426007）](https://item.taobao.com/item.htm?id=631556426007)

**参考图片：**

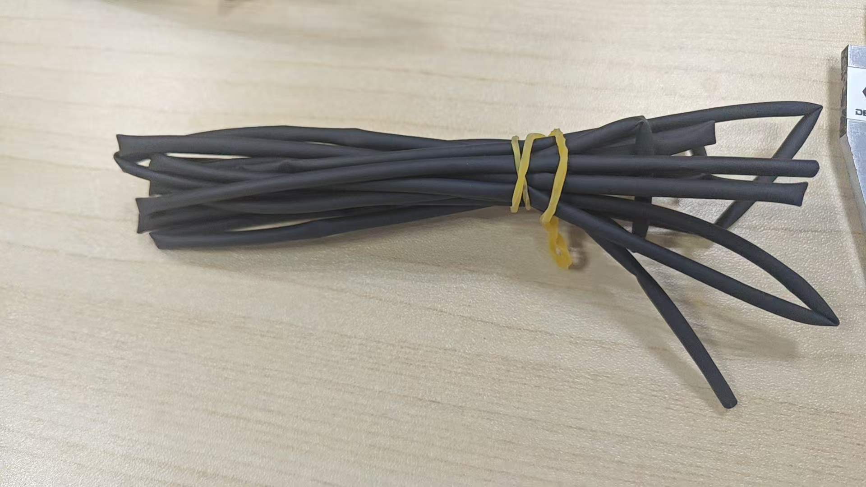
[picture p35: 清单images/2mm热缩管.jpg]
2mm 热缩管


[返回硬件清单](#hardware-list)

### 热缩管：黑色，圆直径 25mm

**功能简介：** 用于 DC-DC 模块焊点和较大接头位置的绝缘保护，减少焊点裸露、磨损和意外短路风险。

**规格：** 黑色，圆直径 25mm。

**参考图片：**

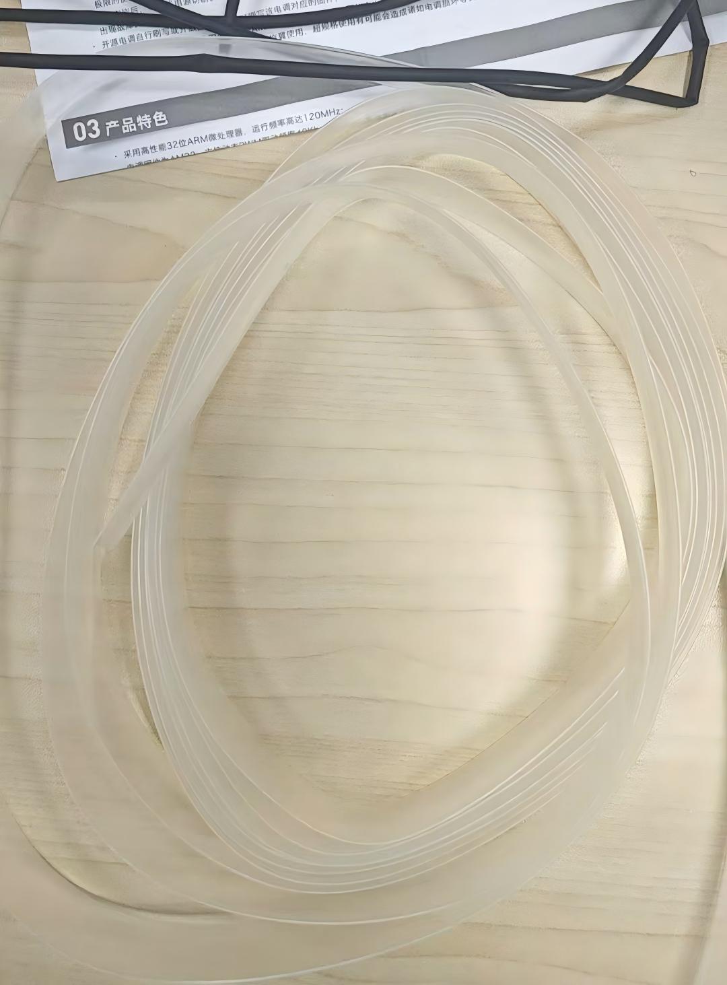
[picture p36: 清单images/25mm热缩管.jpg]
25mm 热缩管


[返回硬件清单](#hardware-list)

### 3K 东丽碳纤维板定制加工

**功能简介：** 用于定制无人机机架、固定翼结构件或其他需要高强度、轻量化的板材部件。

**规格：** 3K 东丽碳纤维板，黑色，固定翼定制加工。订单表中的商品数量为 440，疑似为定制尺寸或计价单位，本清单按 1 项材料订单记录。

**淘宝购买链接：**

[点击查看商品（商品 ID：40340403528）](https://item.taobao.com/item.htm?id=40340403528)

**参考图片：**

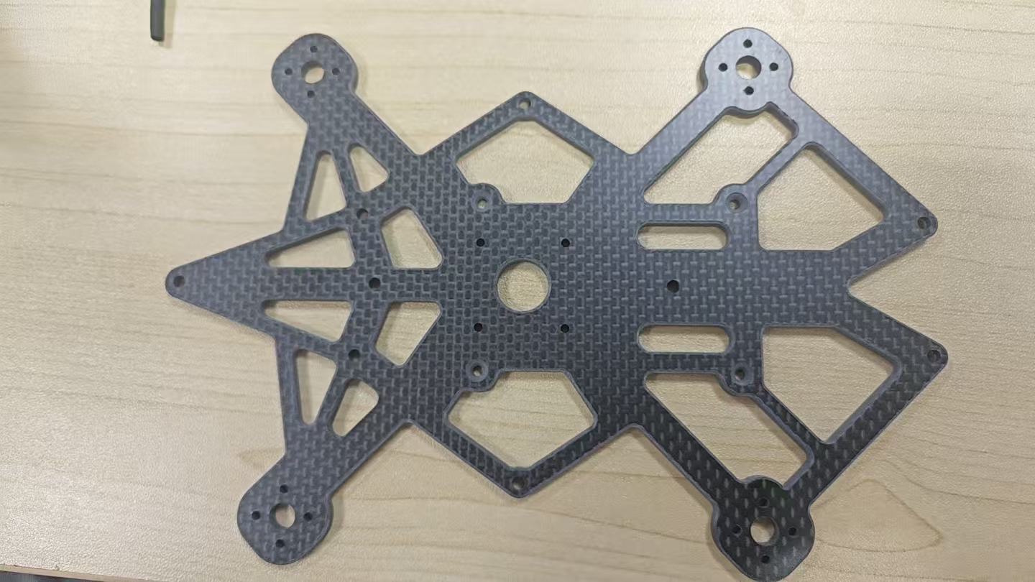
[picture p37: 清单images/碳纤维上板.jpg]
碳纤维上板


[返回硬件清单](#hardware-list)

### PETG 3D 打印定制件

**功能简介：** 用于制作无人机安装支架、保护件、线束固定件和其他定制结构件。

**规格：** PETG 材料，3D 打印定制加工，数量 6。

**淘宝购买链接：**

[点击查看商品（商品 ID：809701547241）](https://item.taobao.com/item.htm?id=809701547241)

**参考图片：**

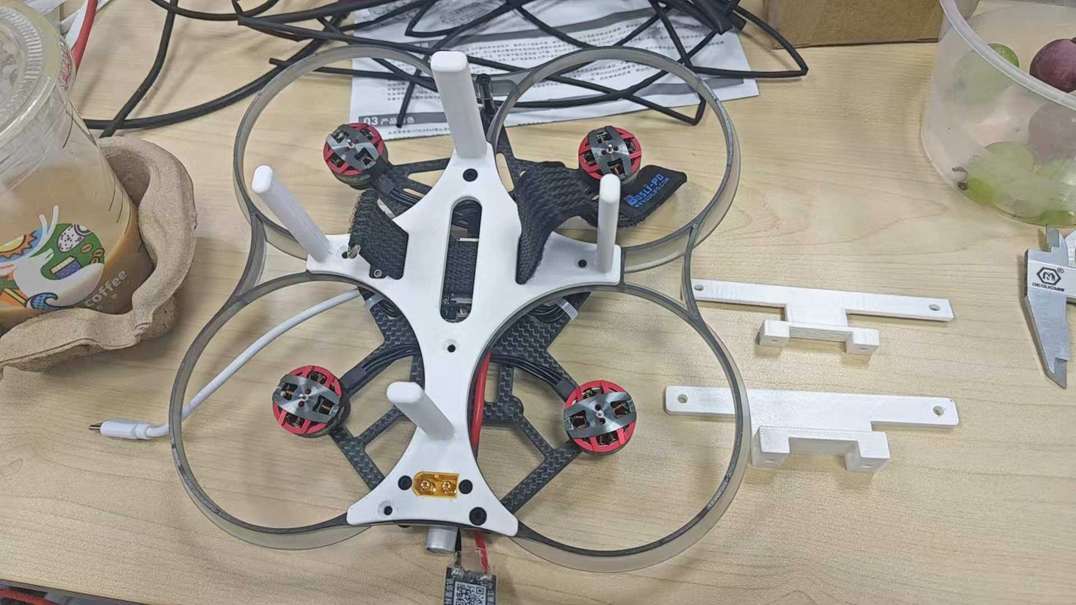
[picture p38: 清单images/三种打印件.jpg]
PETG 3D 打印件


[返回硬件清单](#hardware-list)

### BB 响

**功能简介：** 作为飞控的声音提示器，用于低电量、解锁状态、失控或定位提示。

**参考图片：**

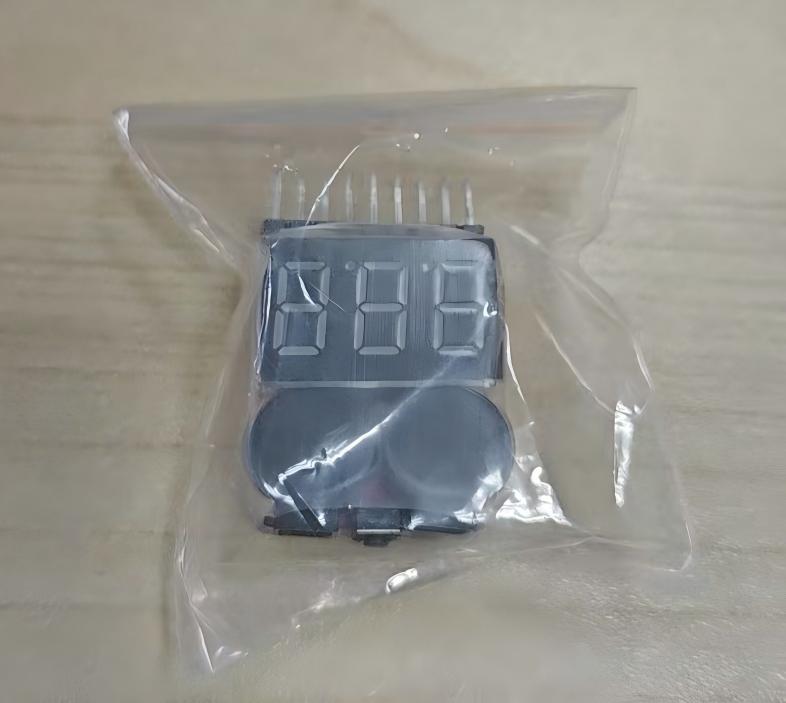
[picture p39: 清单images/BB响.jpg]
BB 响


**淘宝购买链接：**

[点击查看 BB 响商品（SKU：5619084980840）](https://item.taobao.com/item.htm?id=843832893059&skuId=5619084980840)

[返回硬件清单](#hardware-list)

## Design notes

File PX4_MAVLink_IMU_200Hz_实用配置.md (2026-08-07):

# PX4 将 MAVROS IMU 频率提高到约 200 Hz

## 1. 在 QGroundControl 中修改 IMU 内部频率

设备：**安装 QGroundControl 的电脑**

连接：**电脑通过 USB 连接飞控**

打开：

**QGroundControl → Analyze Tools → MAVLink Console**

输入：

```bash
param set IMU_INTEG_RATE 400
param save
reboot
```

飞控重启并重新连接后，在 MAVLink Console 输入：

```bash
param show IMU_INTEG_RATE
```

确认显示：

```text
IMU_INTEG_RATE : 400
```

再输入：

```bash
uorb top vehicle_imu
```

确认 `vehicle_imu` 频率大于 200 Hz。

本机实测约：

```text
293~294 Hz
```

## 2. 临时测试机载电脑 MAVLink IMU 频率

设备：**安装 QGroundControl 的电脑**

界面：

**QGroundControl → Analyze Tools → MAVLink Console**

机载电脑连接的飞控串口为：

```text
/dev/ttyS1 @ 921600
```

输入：

```bash
mavlink stream -d /dev/ttyS1 -s HIGHRES_IMU -r 250
```

检查：

```bash
mavlink status streams
```

确认 `instance #0` 中显示：

```text
HIGHRES_IMU    250.00 (250.000)
```

再输入：

```bash
mavlink status
```

确认 `instance #0`：

```text
txerr: 0.0 B/s
tx rate mult: 1.000
```

## 3. 在机载电脑确认实际频率

设备：**机载电脑**

先启动 MAVROS。

然后终端输入：

```bash
rostopic hz /mavros/imu/data_raw
```

确认实际频率约为：

```text
200 Hz
```

## 4. 设置飞控每次开机自动配置 250 Hz

设备：**安装 QGroundControl 的电脑**

界面：

**QGroundControl → Analyze Tools → MAVLink Console**

先确认 SD 卡：

```bash
ls /fs/microsd
```

创建启动脚本目录：

```bash
mkdir /fs/microsd/etc
```

创建自动启动文件：

```bash
echo "set +e" > /fs/microsd/etc/extras.txt
echo "mavlink stream -d /dev/ttyS1 -s HIGHRES_IMU -r 250" >> /fs/microsd/etc/extras.txt
echo "set -e" >> /fs/microsd/etc/extras.txt
```

检查文件：

```bash
cat /fs/microsd/etc/extras.txt
```

应该显示：

```text
set +e
mavlink stream -d /dev/ttyS1 -s HIGHRES_IMU -r 250
set -e
```

然后重启飞控：

```bash
reboot
```

## 5. 重启后最终检查

设备：**安装 QGroundControl 的电脑**

进入：

**QGroundControl → Analyze Tools → MAVLink Console**

不要再手动设置频率，直接输入：

```bash
param show IMU_INTEG_RATE
```

确认：

```text
IMU_INTEG_RATE : 400
```

输入：

```bash
mavlink status streams
```

确认 `instance #0`：

```text
HIGHRES_IMU    250.00 (250.000)
```

然后在机载电脑输入：

```bash
rostopic hz /mavros/imu/data_raw
```

确认：

```text
约 200 Hz
```

## 最终配置

```text
IMU_INTEG_RATE = 400

机载电脑 MAVLink：
/dev/ttyS1 @ 921600

HIGHRES_IMU：
目标频率 = 250 Hz

MAVROS：
/mavros/imu/data_raw ≈ 200 Hz
```

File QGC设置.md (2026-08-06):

# QGC 设置

| 步骤 | 内容 | 媒体 | 详情 |
|---:|---|---|---|
| 0 | 接收机与遥控器对频 | 视频 | [查看详细介绍](#step-00-radio-bind) |
| 1 | 打开 QGroundControl 并连接飞控 | 图片 | [查看详细介绍](#step-01-open-qgc) |
| 2 | 进入 Configure / 配置页面 | 图片 | [查看详细介绍](#step-02-configure-page) |
| 3 | 遥控器通道校准 | 图片 | [查看详细介绍](#step-03-radio-calibration) |
| 4 | 飞行模式与开关设置 | 图片 | [查看详细介绍](#step-04-flight-mode) |
| 5 | Actuators / 电机电调设置 | 图片 | [查看详细介绍](#step-05-actuators) |
| 6 | 传感器方向与校准设置 | 图片 | [查看详细介绍](#step-06-sensors) |

## QGC 设置详细介绍

### 第 0 步、接收机与遥控器对频

**用到的材料：** 遥控器、接收机、已安装好的无人机或单独接收机供电环境。

**步骤目标：** 让接收机和遥控器完成对频，保证后续 QGC 能读取遥控器通道输入。

**操作演示：**

<video controls src="QGC配置images/第0步接收机遥控器对频.mp4" width="100%"></video>

[无法播放视频时，点击打开第 0 步视频](QGC配置images/第0步接收机遥控器对频.mp4)

**操作流程：**

> 在这里补充第 0 步的具体操作流程。

1. 待填写：
2. 待填写：
3. 待填写：

**注意事项：** 对频完成后，先确认遥控器和接收机指示灯状态正常，再进入 QGC 进行通道检查。

[返回 QGC 设置目录](#qgc-setup-list)

### 第 1 步、打开 QGroundControl 并连接飞控

**用到的材料：** 已安装好的无人机、飞控 USB 线、电脑、QGroundControl。

**步骤目标：** 打开 QGC，确认飞控已连接，进入主界面。

**步骤图片：**

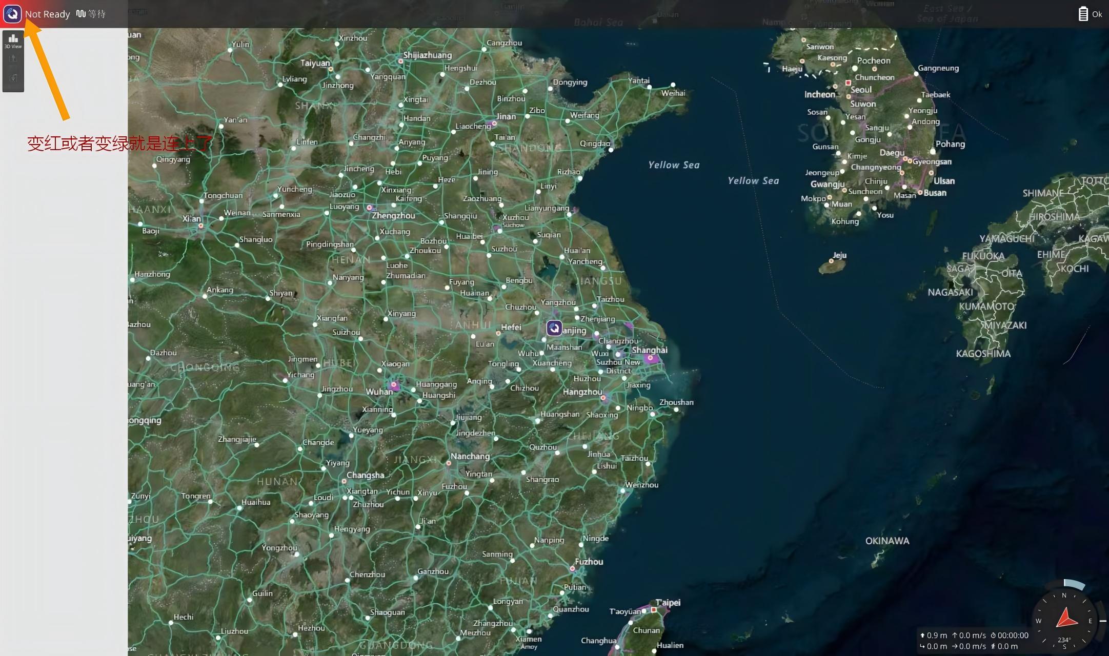
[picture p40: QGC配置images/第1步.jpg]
第 1 步：打开 QGroundControl 并连接飞控


**操作流程：**

> 在这里补充第 1 步的具体操作流程。

1. 待填写：
2. 待填写：
3. 待填写：

**注意事项：** 连接飞控和配置参数时先不要安装桨叶，避免误触发电机造成危险。

[返回 QGC 设置目录](#qgc-setup-list)

### 第 2 步、进入 Configure / 配置页面

**用到的材料：** 已连接 QGC 的飞控、电脑。

**步骤目标：** 从 QGC 主菜单进入 Configure / 配置页面，开始车辆设置。

**步骤图片：**

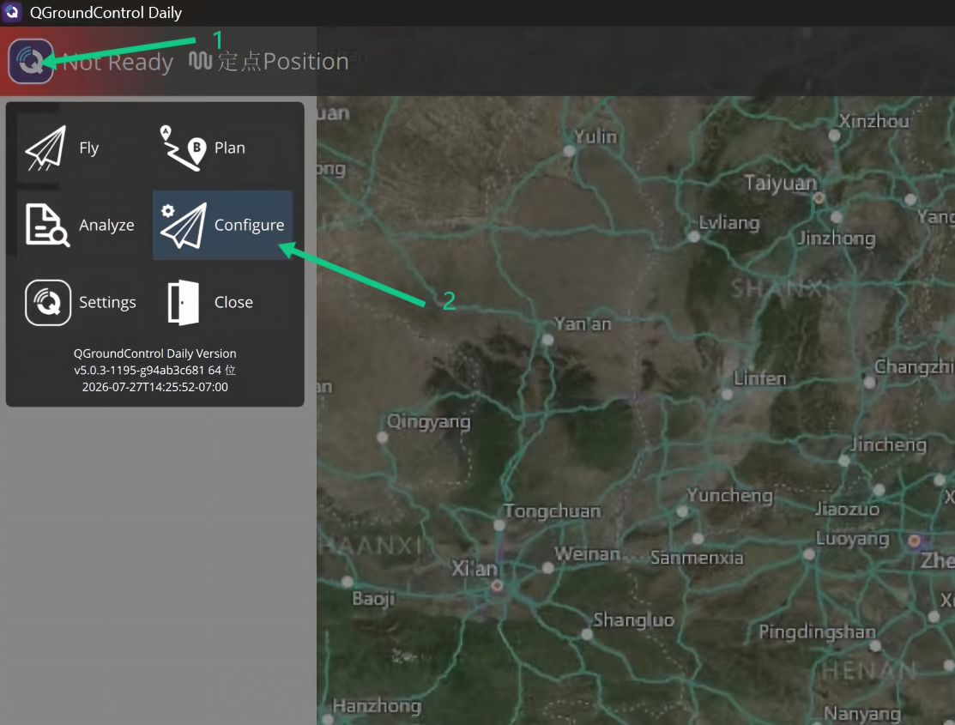
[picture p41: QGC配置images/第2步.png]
第 2 步：进入 Configure 配置页面


**操作流程：**

> 在这里补充第 2 步的具体操作流程。

1. 待填写：
2. 待填写：
3. 待填写：

**注意事项：** 如果 QGC 没有显示 Configure / 配置入口，先确认飞控是否已经正常连接并完成参数下载。

[返回 QGC 设置目录](#qgc-setup-list)

### 第 3 步、遥控器通道校准

**用到的材料：** 遥控器、接收机、已连接 QGC 的飞控。

**步骤目标：** 让 QGC 正确识别油门、横滚、俯仰、偏航以及辅助通道。

**步骤图片：**

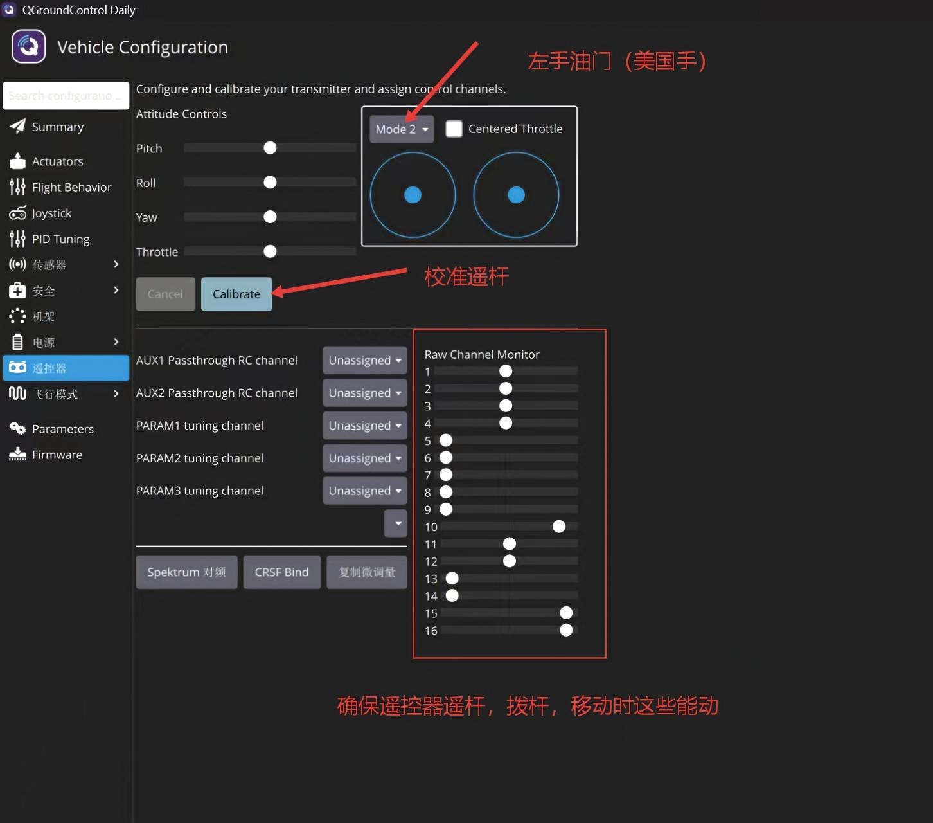
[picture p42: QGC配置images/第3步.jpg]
第 3 步：遥控器通道校准


**操作流程：**

> 在这里补充第 3 步的具体操作流程。

1. 待填写：
2. 待填写：
3. 待填写：

**注意事项：** 校准时观察 Raw Channel Monitor / 原始通道监视器，确认摇杆和开关动作都能被 QGC 识别。

[返回 QGC 设置目录](#qgc-setup-list)

### 第 4 步、飞行模式与开关设置

**用到的材料：** 遥控器、已连接 QGC 的飞控。

**步骤目标：** 绑定飞行模式通道、解锁开关、Offboard 开关等常用控制开关。

**步骤图片：**

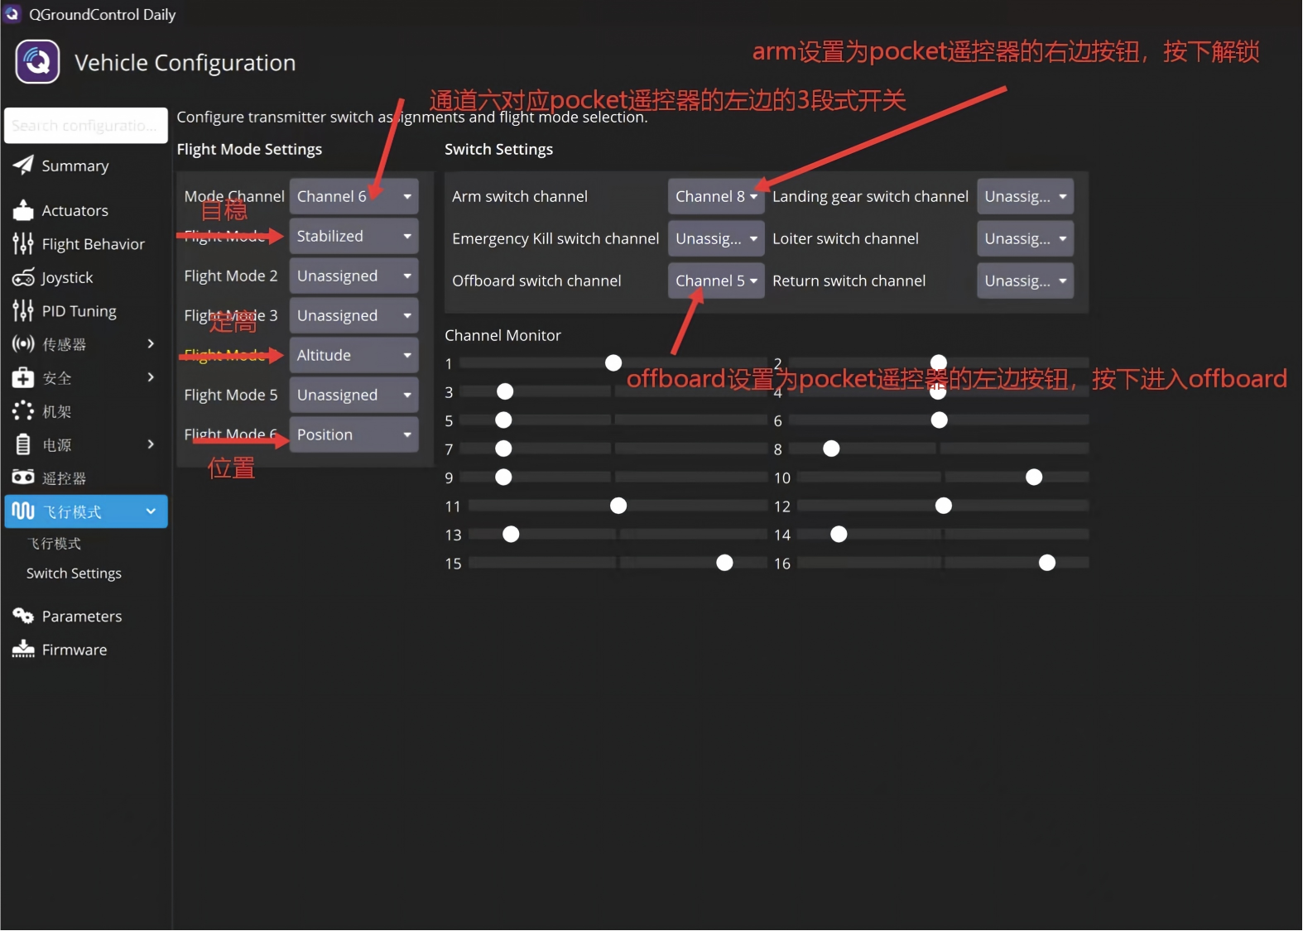
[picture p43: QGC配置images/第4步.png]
第 4 步：飞行模式与开关设置


**操作流程：**

> 在这里补充第 4 步的具体操作流程。

1. 待填写：
2. 待填写：
3. 待填写：

**注意事项：** 首次测试建议至少保留一个稳定类飞行模式，并确认解锁开关方向符合预期。

[返回 QGC 设置目录](#qgc-setup-list)

### 第 5 步、Actuators / 电机电调设置

**用到的材料：** 已焊接完成的电机、电调、飞控、电池、QGroundControl。

**步骤目标：** 设置电机数量、输出通道、电调协议和电机方向，确认电机编号与机架图一致。

**步骤图片：**

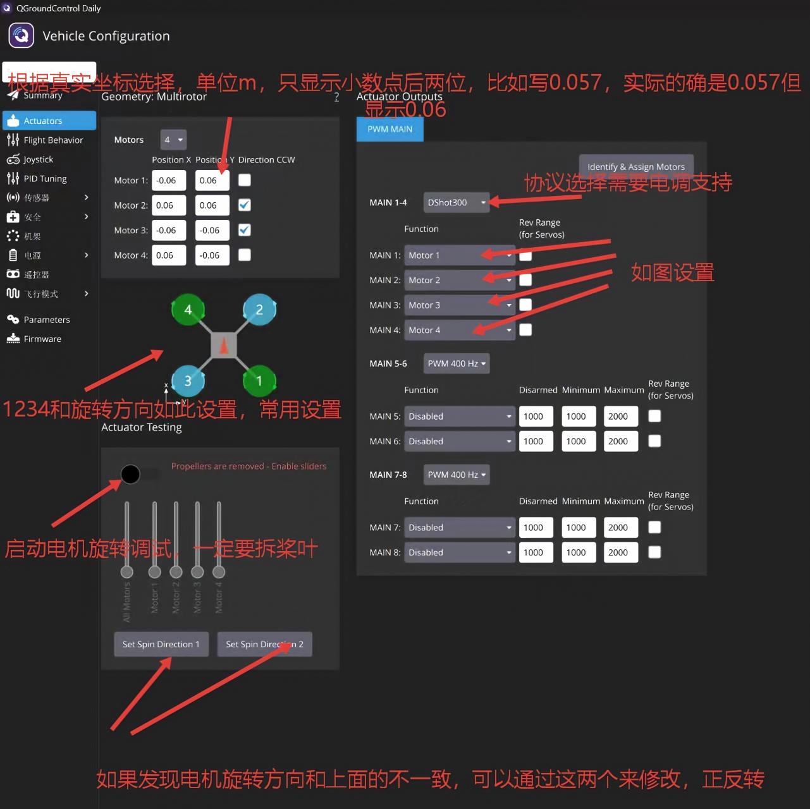
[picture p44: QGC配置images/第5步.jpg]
第 5 步：Actuators 电机电调设置


**操作流程：**

> 在这里补充第 5 步的具体操作流程。

1. 待填写：
2. 待填写：
3. 待填写：

**注意事项：** 所有电机测试、ESC 校准、执行器测试都必须拆桨。电机只需要低油门短时间确认，不要长时间空转。

[返回 QGC 设置目录](#qgc-setup-list)

### 第 6 步、传感器方向与校准设置

**用到的材料：** 已安装好的无人机、平整桌面、QGroundControl，必要时准备远离强磁场的空旷位置。

**步骤目标：** 设置飞控安装方向，并完成陀螺仪、加速度计、水平和罗盘等传感器校准。

**步骤图片：**

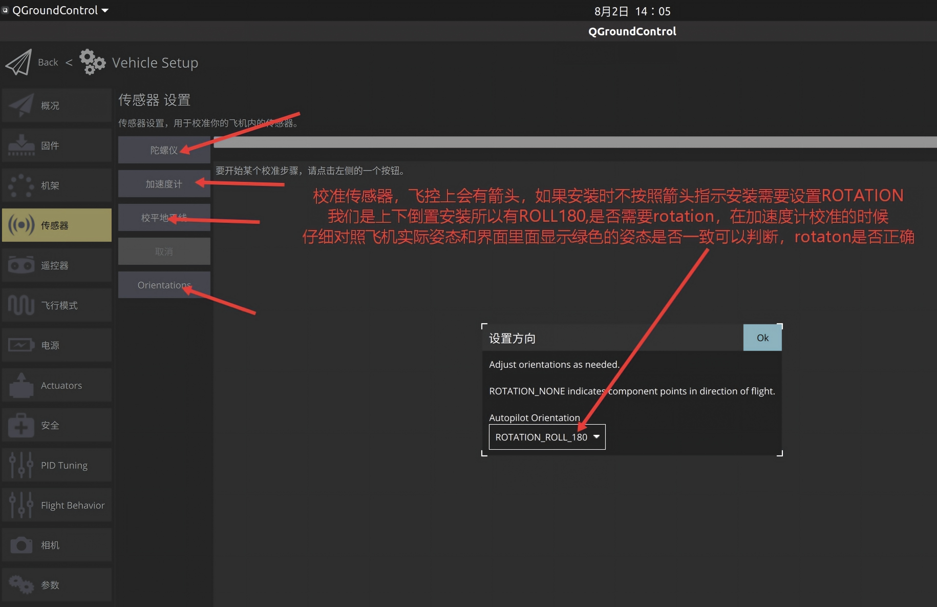
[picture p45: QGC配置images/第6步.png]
第 6 步：传感器方向与校准设置


**操作流程：**

> 在这里补充第 6 步的具体操作流程。

1. 待填写：
2. 待填写：
3. 待填写：

**注意事项：** 罗盘校准失败时不要直接飞行。先换一个远离磁干扰的位置，再检查飞控、电源线、电调和电池是否离罗盘太近。

[返回 QGC 设置目录](#qgc-setup-list)

## 配置后检查

1. 遥控器通道方向、油门最低位、解锁开关和飞行模式切换正常。
2. 电机编号、旋转方向、电调协议和输出通道与实际硬件一致。
3. 飞控安装方向、机头方向和 QGC 姿态显示一致。
4. QGC 顶部状态栏没有关键红色告警后，再进行后续地面测试。

## 参考资料

- [QGroundControl Radio Setup](https://docs.qgroundcontrol.com/master/en/qgc-user-guide/setup_view/radio.html)
- [QGroundControl Motor Setup](https://docs.qgroundcontrol.com/master/en/qgc-user-guide/setup_view/motors.html)
- [QGroundControl Sensors](https://docs.qgroundcontrol.com/master/en/qgc-user-guide/setup_view/sensors.html)
- [QGroundControl First Flight Guide](https://docs.qgroundcontrol.com/master/en/qgc-user-guide/getting_started/quick_start.html)
- [PX4 Actuator Configuration and Testing](https://docs.px4.io/main/en/config/actuators)

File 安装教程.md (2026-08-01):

# 无人机安装教程

| 步骤 | 内容 | 详情 |
|---:|---|---|
| 1 | 安装上板螺柱 | [查看详细介绍](#step-01-top-standoff) |
| 2 | 安装电机 | [查看详细介绍](#step-02-motor) |
| 3 | 去除电调上自带的电容 | [查看详细介绍](#step-03-remove-esc-capacitor) |
| 4 | 焊接电机线到电调上 | [查看详细介绍](#step-04-solder-motor-wires) |
| 5 | 组装，安装飞塔 | [查看详细介绍](#step-05-stack) |
| 6 | 理清楚线后用扎带扎紧电机线 | [查看详细介绍](#step-06-tie-motor-wires) |
| 7 | 修复电调和飞控 8pin 控制线引脚不对齐问题，并安装修复后的控制线 | [查看详细介绍](#step-07-fix-8pin-cable) |
| 8 | 连接 DC-DC 变换器输入线与电调电源线，并把电调电源线焊接在 XT60E1-M 上，然后安装电容 | [查看详细介绍](#step-08-power-wiring) |
| 9 | 安装接收机 | [查看详细介绍](#step-09-receiver) |
| 10 | 制作飞控调试 Type-C 口延长线并安装 | [查看详细介绍](#step-10-debug-typec-extension) |
| 11 | 安装电池绑带，组装上板、桨叶保护圈和下板，并固定 XT60E1-M 和 Type-C 延长母座 | [查看详细介绍](#step-11-frame-assembly) |
| 12 | 焊接 DC-DC 变换器和 XT30 母头 | [查看详细介绍](#step-12-dcdc-xt30) |
| 13 | 安装深度相机 | [查看详细介绍](#step-13-depth-camera) |
| 14 | 安装机载电脑 | [查看详细介绍](#step-14-onboard-computer) |

## 安装详细介绍

### 1、安装上板螺柱

**用到的材料：** 上板连接螺柱、M3×12mm 铝合金支柱7颗、M3×10mm 沉头螺丝7颗。

**详细说明：** 按机架孔位安装 M3 螺柱。

**参考图片：**

第 1 步：安装上板螺柱 1.1

**操作流程：** 这面定义为正面，上方是机头。

**参考图片：**

第 1 步：安装上板螺柱 1.2

**操作流程：** 这面定义为反面，上方是机头。

[返回安装目录](#install-list)

### 2、安装电机

**用到的材料：** OddityRC 2006 2150KV 无刷电机、配套电机固定螺丝（4颗短的用来安装电机，2颗长的安装桨叶）、机架电机安装位。

**详细说明：** 安装前确认电机孔位和机架正反面，电机安装在反面；固定时注意螺丝长度，避免螺丝顶到电机绕组。所有电机先轻锁定位，确认无误后再逐个锁紧，按对角线顺序安装螺丝。

**参考图片：**

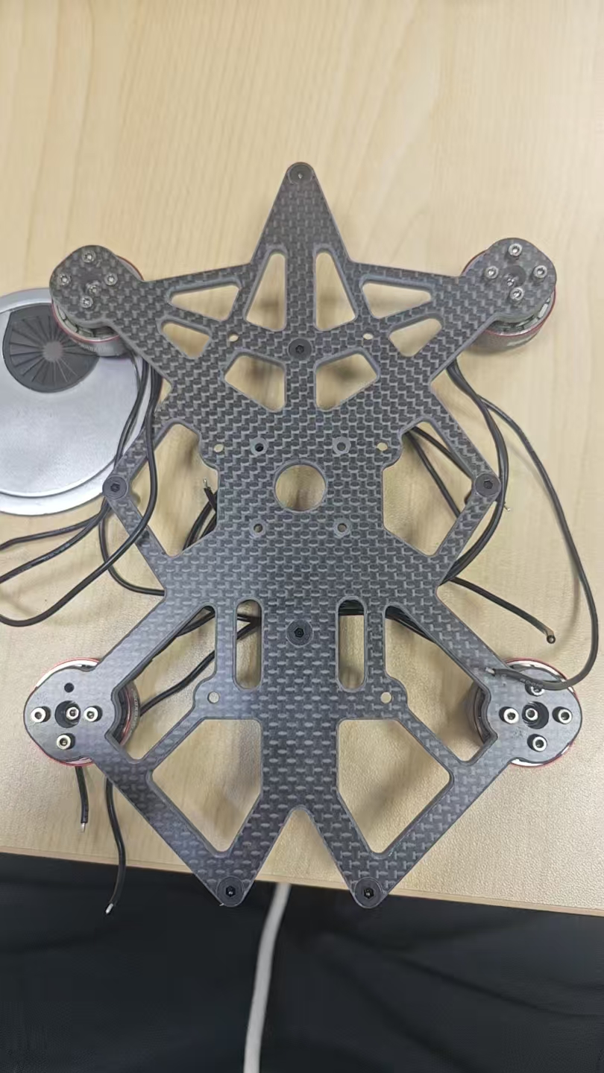
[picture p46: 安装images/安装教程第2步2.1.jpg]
第 2 步：安装电机 2.1


**操作流程：** 按照对角线优先安装的顺序安装螺丝，注意别让螺丝顶到漆包线，这面定义为正面，这款飞机是电机倒置款式。

**参考图片：**

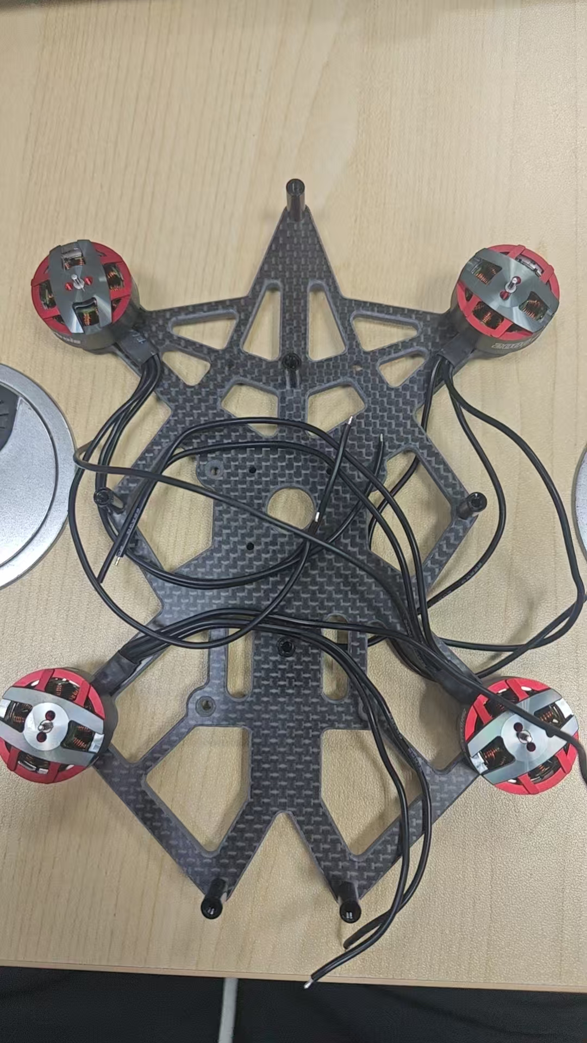
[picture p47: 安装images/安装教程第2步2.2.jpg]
第 2 步：安装电机 2.2


**操作流程：** 这面定义为反面。

[返回安装目录](#install-list)

### 3、去除电调上自带的电容

**用到的材料：** 45A 四合一电调、电烙铁、焊锡、钳子。

**详细说明：** 操作前确认电调完全断电，并记录原电容正负极方向。拆除时避免长时间加热焊盘，防止焊盘脱落；在去除黑色注胶后，双人操作，一人负责加热焊点，一人负责在电容松动后用钳子取下电容。

**参考图片：**

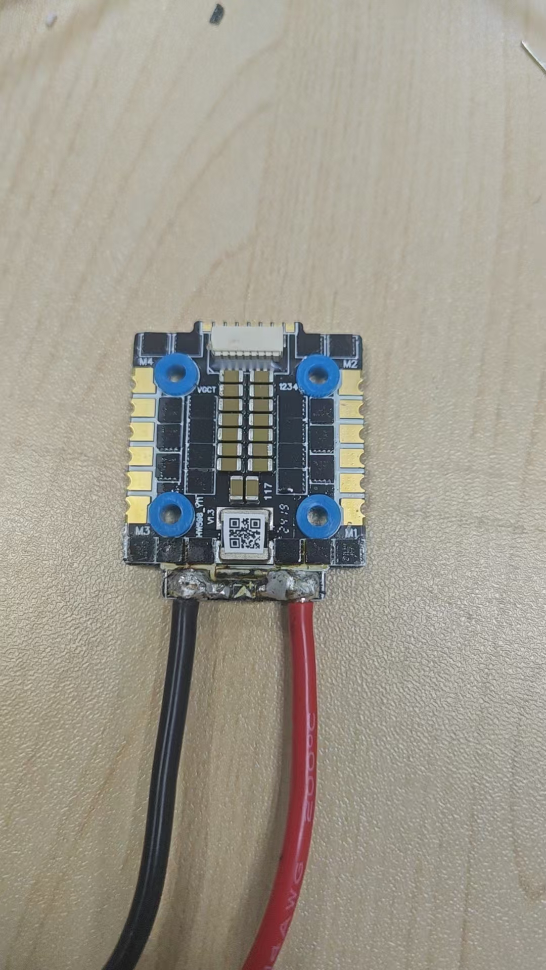
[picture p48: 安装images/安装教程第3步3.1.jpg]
第 3 步：去除电调上自带的电容 3.1


**操作流程：** 右边红色正级与边上铁条链接属于正常情况，铁条是电流采样电阻mΩ级别，串联在电路中的。

[返回安装目录](#install-list)

### 4、焊接电机线到电调上

**用到的材料：** 四个无刷电机、45A 四合一电调、焊锡丝、电烙铁。

**详细说明：** 焊接前先按电机位置整理线长，尽量保持左右对称和走线清晰。三相线初始顺序可以先按方便焊接排列，后续可在飞控或电调配置中调整电机方向；焊完后检查是否有虚焊、连锡和线皮烫伤，注意电调上的M1,M2,M3,M4丝印要与电机实际安装方位对应，电调，要预先上锡，这是通用电机安装方式，QGC地面站设置要与实际情况对应。

**参考图片：**

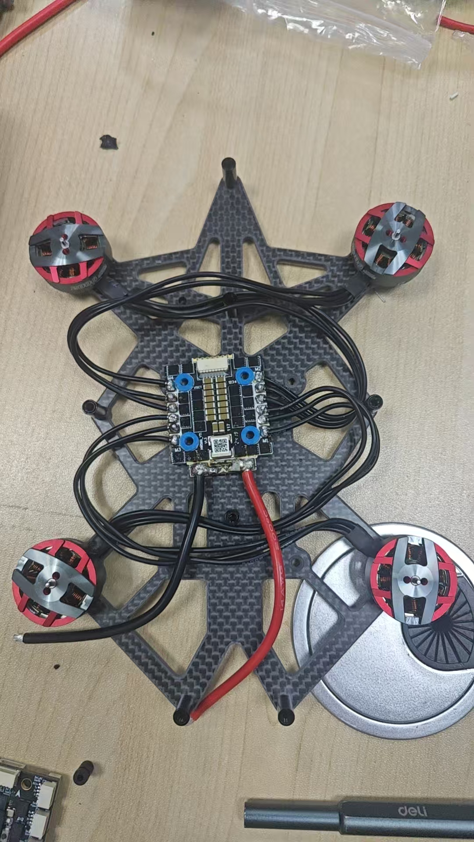
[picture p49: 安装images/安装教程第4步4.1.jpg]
第 4 步：焊接电机线到电调上 4.1


**操作流程：** 这是反面左下是1号电机，左上是2号，右下是3号，右上是4号。

**参考图片：**

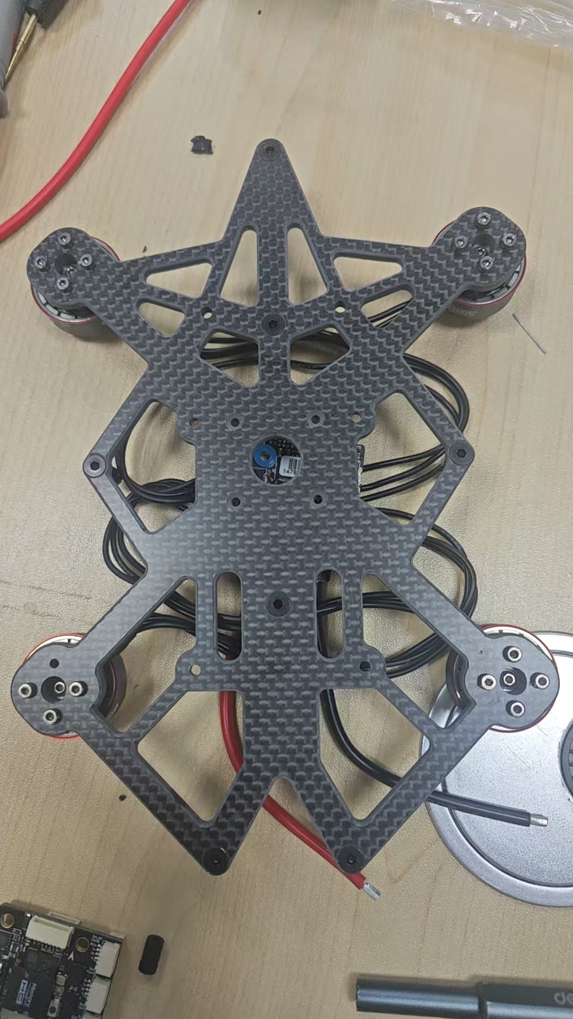
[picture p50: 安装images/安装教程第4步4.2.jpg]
第 4 步：焊接电机线到电调上 4.2


**操作流程：** 这是正面右下是1号电机，右上是2号，左下是3号，左上是4号。

[返回安装目录](#install-list)

### 5、组装，安装飞塔

**用到的材料：** 飞控 NxtPX4、45A 四合一电调、尼龙螺丝4颗、尼龙螺母8颗、飞控减震硅胶柱。

**详细说明：** 安装时保持飞控箭头方向与机头一致，确认减震、螺丝长度和板间距合适。锁紧前检查电调、飞控、线束和碳板之间没有短路风险，电调安装在靠近碳板侧，飞控安装在远离碳板侧。

**参考图片：**

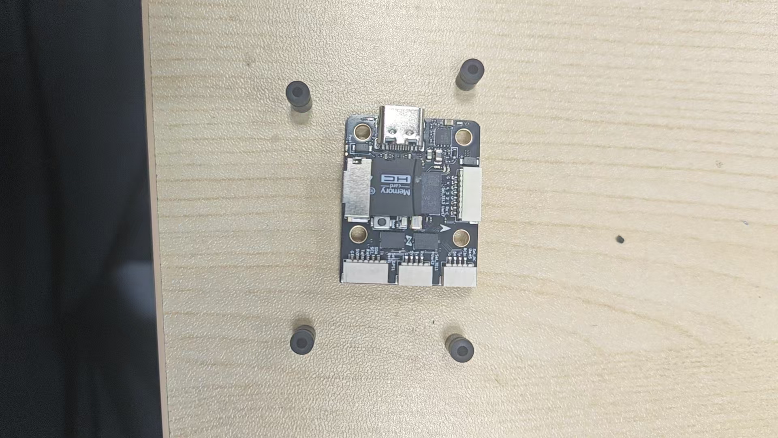
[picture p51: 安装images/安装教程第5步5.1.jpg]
第 5 步：组装安装飞塔 5.1


**操作流程：** 首先要塞硅胶减震柱，可以用小的螺丝刀塞。

**参考图片：**

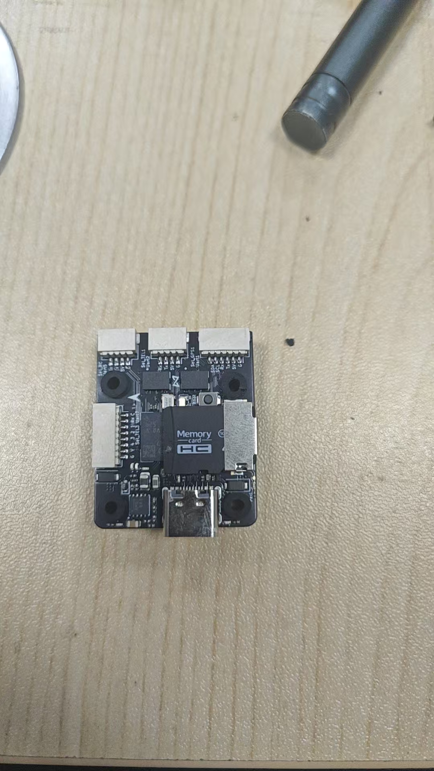
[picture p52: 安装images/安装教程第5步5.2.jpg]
第 5 步：组装安装飞塔 5.2


**操作流程：** 塞好的效果图。

**参考图片：**

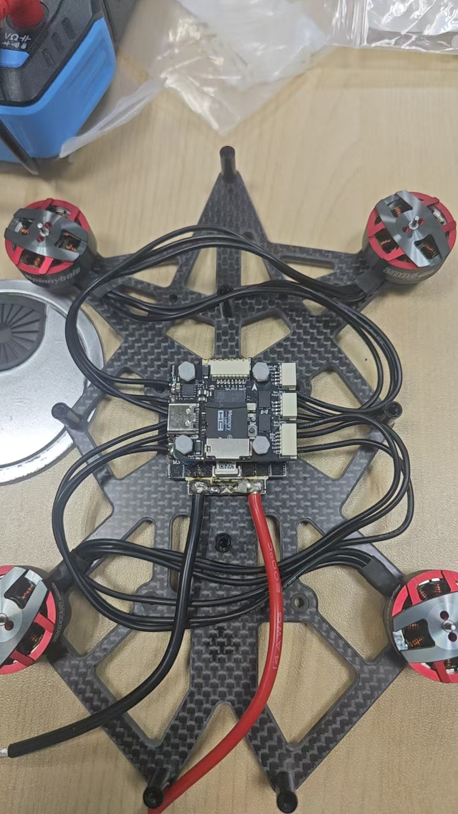
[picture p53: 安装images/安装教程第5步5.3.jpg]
第 5 步：组装安装飞塔 5.3


**操作流程：** 首先拿尼龙螺柱穿过碳板电调和飞控，然后拧上两个尼龙螺母，塞的时候力气小点，尼龙螺柱很容易被折弯曲。

[返回安装目录](#install-list)

### 6、理清楚线后用扎带扎紧电机线

**用到的材料：** 已焊接好的电机线、尼龙扎带。

**详细说明：** 线束应沿机架边缘或预定走线路径布置，保留少量维修余量。扎带锁紧后剪掉多余尾部，剪口不要朝向线材，避免飞行振动时磨破绝缘层。

**参考图片：**

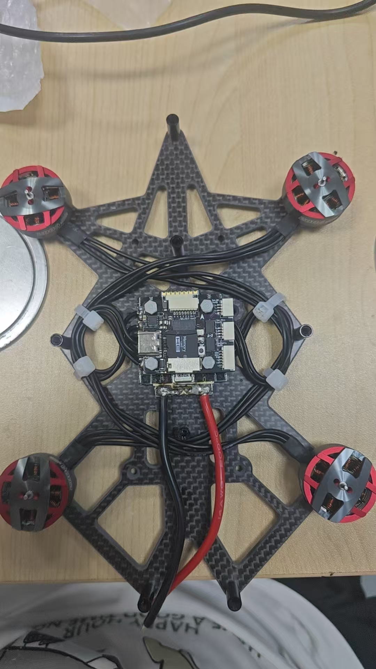
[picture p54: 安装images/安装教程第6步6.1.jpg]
第 6 步：扎紧电机线 6.1


**操作流程：** 照着图理或者别的方式理都行。

[返回安装目录](#install-list)

### 7、修复电调和飞控 8pin 控制线引脚不对齐问题，并安装修复后的控制线

**用到的材料：** 8pin 控制线、烙铁、焊锡丝、2mm热缩管、助焊剂、剪刀、万用表。

**详细说明：** 先分别查清飞控端和电调端的 8pin 定义，包括电源、地线、电流检测、通信和四路电机信号。按实际定义重新调整线序，安装前用万用表确认连续性和是否短路，再接入飞控与电调。

**参考图片：**

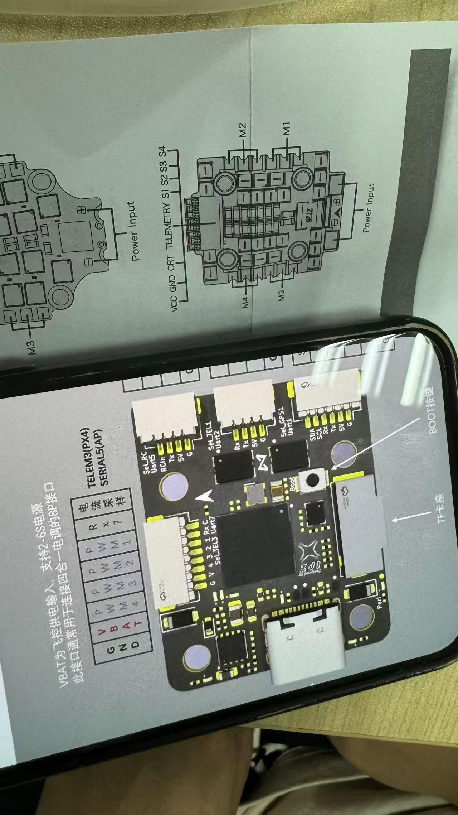
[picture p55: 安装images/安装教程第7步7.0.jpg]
第 7 步：8pin 控制线修复 7.0


**操作流程：** 飞控和电调不是一个厂家，引脚定义不同这是原理图，手机屏幕里的是飞控，纸上的是电调。

**参考图片：**

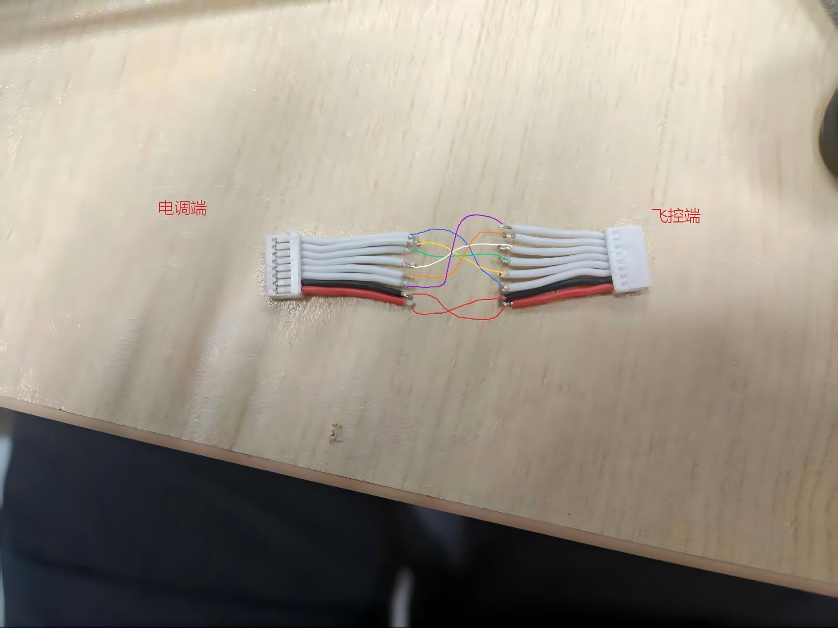
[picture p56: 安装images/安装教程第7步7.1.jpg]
第 7 步：8pin 控制线修复 7.1


**操作流程：** 接线图。

**参考图片：**

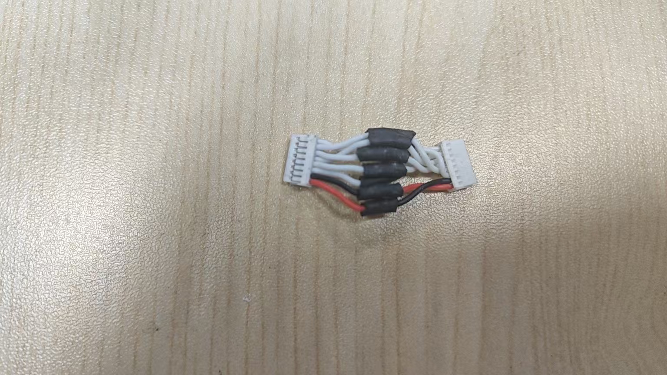
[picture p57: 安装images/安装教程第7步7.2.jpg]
第 7 步：8pin 控制线修复 7.2


**操作流程：** 接好的样子。

**参考图片：**

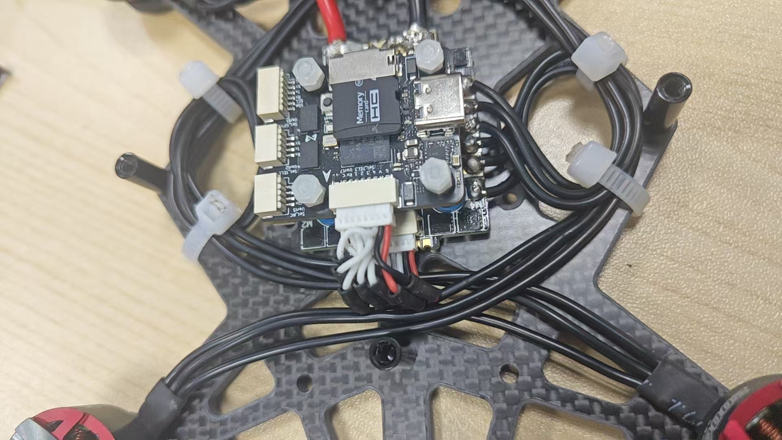
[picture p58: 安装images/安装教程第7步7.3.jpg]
第 7 步：8pin 控制线修复 7.3


**操作流程：** 插上的样子。

[返回安装目录](#install-list)

### 8、连接 DC-DC 变换器输入线与电调电源线，并把电调电源线焊接在 XT60E1-M 上，然后安装电容

**用到的材料：** 电调电源线、XT60E1-M、固态电容、18AWG 电源线、电工胶布、烙铁、焊锡丝、剥线钳。

**详细说明：** 将作为DC-DC 输入的18awg线并接到电调电源线，电调主电源线焊接到 XT60E1-M；所有电源焊点都要确认正负极。电容安装在电源输入附近，注意极性和固定方式，避免引脚裸露接触碳板，XT60E1-M预先上锡，刚刚填上那个小洞就行，18awg电线要拨出来一部分电线分成两束，电调电源线也播出来一部分，然后把18awg线缠绕在电调电源线上，然后上锡，然后把电调电源线焊在公头上，然后在合适的位置焊上电容，电容位置要确保第11步不影响安装，之后缠绕电工胶布。

**参考图片：**

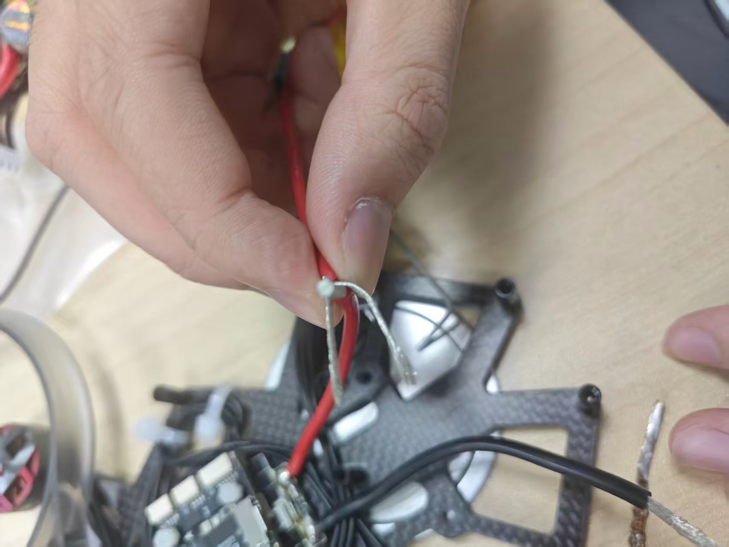
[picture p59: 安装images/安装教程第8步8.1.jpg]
第 8 步：电源线与电容安装 8.1


**操作流程：** 先拨开合适的长度，然后把18awg分成两股然后缠到拨开合适长度的电调电源线上。

**参考图片：**

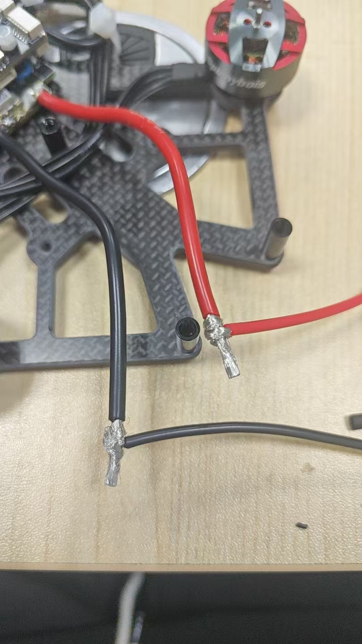
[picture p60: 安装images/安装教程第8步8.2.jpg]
第 8 步：电源线与电容安装 8.2


**操作流程：** 缠绕效果。

**参考图片：**

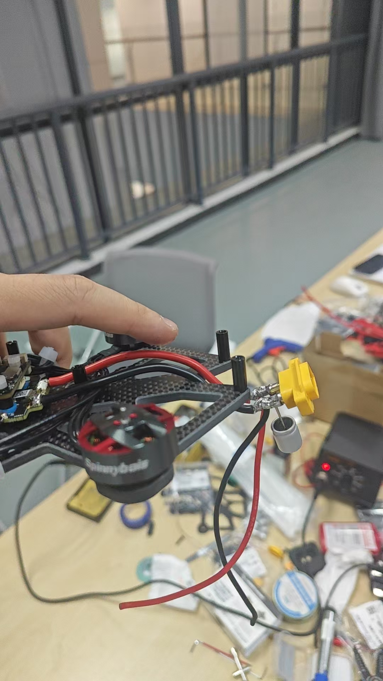
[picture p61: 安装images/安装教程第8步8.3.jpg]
第 8 步：电源线与电容安装 8.3


**操作流程：** 缠绕点焊上，然后给XT60预先上锡，把里面的小坑刚刚填满就行，然后焊好xt60以后，先照着11步看看，怎么装电容合适，在焊电容。

[返回安装目录](#install-list)

### 9、安装接收机

**用到的材料：** 接收机、接收机连接线、魔术贴或尼龙扎带。

**详细说明：** 将接收机固定在机架内相对远离电调和大电流电源线的位置，天线尽量避开碳板遮挡。按飞控接口定义连接电源、地线和信号线，固定后确认线束不会被上板、桨叶保护圈或其他结构件挤压。

**参考图片：**

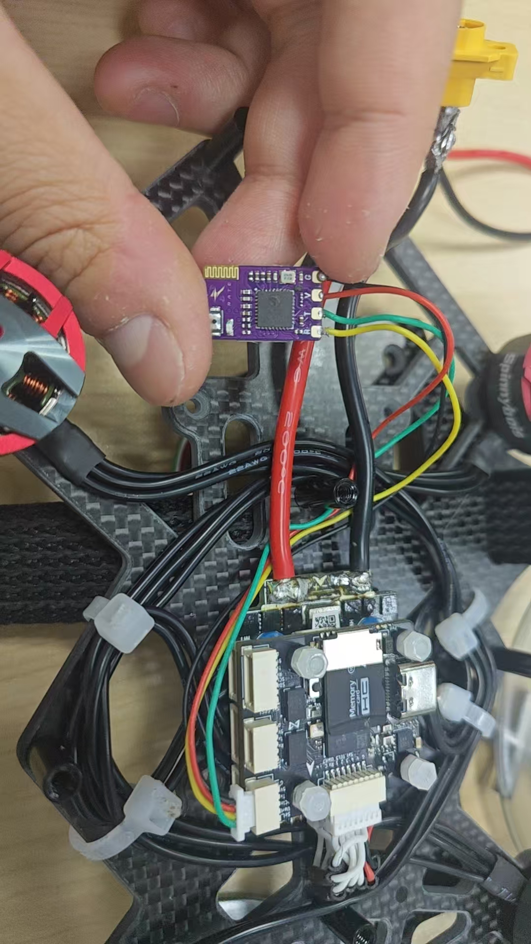
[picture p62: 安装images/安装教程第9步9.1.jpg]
第 9 步：安装接收机 9.1


**操作流程：** 待补充。

**参考图片：**

[返回安装目录](#install-list)

### 10、制作飞控调试 Type-C 口延长线并安装

**用到的材料：** Type-C 调试母座、Type-C（4pin）公头、电工胶布、焊锡丝、烙铁。

**详细说明：** 按飞控调试接口针脚定义制作延长线，并将 Type-C 母座固定在机架下板预留位置。安装后检查插拔方向、线序和连接稳定性，避免调试时反复拆机。

**参考图片：**

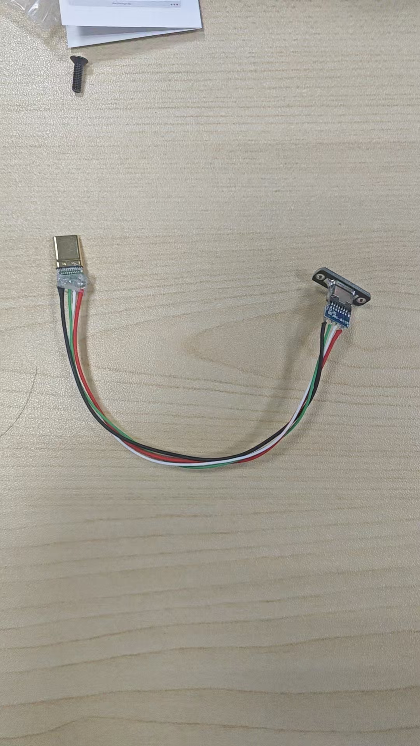
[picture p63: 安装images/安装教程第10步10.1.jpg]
第 10 步：制作调试 Type-C 延长线 10.1


**操作流程：** 可以用热熔胶站上。

第 10 步：安装接收机 10.2

**操作流程：** 线要理一理,注意图中的安装实际上是不合理的！！！！，不能用螺丝，螺母固定，这会导致第11步骤无法安装，请不要照着图中的办法固定死母座，直接不管他就行，露出来一节也没事，不行的原因主要是，母座和公头安装以后会发生碰撞导致没法合上底板。

[返回安装目录](#install-list)

### 11、安装电池绑带，组装上板、桨叶保护圈和下板，并固定 XT60E1-M 和 Type-C 延长母座

**用到的材料：** 电池绑带、上板、下板、桨叶保护圈、XT60E1-M、Type-C 延长母座、M3 *20螺丝6颗、M2.5\*10 2两颗、M2.5\*7 沉头螺丝4颗。

**详细说明：** 先穿好电池绑带，再组合上板、桨叶保护圈和下板。XT60E1-M 与 Type-C 延长母座应固定在机架预留位置，XT60E1-M需要拿剪刀切去一个小缺口，以便穿过桨叶保护圈，安装后确认接口不松动、不遮挡线束，也不会和桨叶保护圈干涉。

**参考图片：**

第 11 步：组装机架和固定接口 11.1

**操作流程：** 待补充。

**参考视频：**

<video src="./安装images/安装教程第11步11.2.mp4" controls width="720"></video>

[如果视频无法直接播放，点击查看视频文件](./安装images/安装教程第11步11.2.mp4)

**操作流程：** 待补充。

[返回安装目录](#install-list)

### 12、焊接 DC-DC 变换器和 XT30 母头

**用到的材料：** DC-DC 降压模块、XT30 母头、18AWG 红黑电源线、25mm 热缩管。

**详细说明：** 焊接前先调好或确认 DC-DC 输出电压，红线接正极，黑线接负极。XT30 母头焊接完成后套热缩管绝缘，通电前用万用表确认输出电压和极性。

**参考图片：**

第 12 步：焊接 DC-DC 和 XT30 12.1

**操作流程：** 有个使能引脚要和输入正极连在一起。

**参考图片：**

第 12 步：焊接 DC-DC 和 XT30 12.2

**操作流程：** 焊上就行注意正负。

**参考图片：**

第 12 步：焊接 DC-DC 和 XT30 12.3

**操作流程：** 包个25mm热缩管。

[返回安装目录](#install-list)

### 13、安装深度相机

**用到的材料：** RealSense D455 深度相机、相机 Type-C 线、PETG 相机安装打印件、M4\*8螺丝2颗，M3\*12平头螺丝2颗，M3防松螺母2颗。

**详细说明：** 深度相机应安装在视野无遮挡、结构刚性较好的位置。固定后整理 Type-C 数据线，保证线材不会被桨叶保护圈、上板或其他部件挤压。

**参考图片：**

第 13 步：安装深度相机 13.1

**操作流程：** 待补充。

[返回安装目录](#install-list)

### 14、安装机载电脑

**用到的材料：** Nvidia Orin NX 机载电脑、XT30 供电线、相机 Type-C 线、固定螺丝M2.5*7的沉头螺丝。

**详细说明：** 将机载电脑固定在机架规划位置，连接 XT30 供电线和深度相机 Type-C 线。首次上电前确认 DC-DC 输出电压稳定、接口极性正确，并检查线束不会影响机架闭合。

**参考图片：**

第 14 步：安装机载电脑 14.1

**操作流程：** 装机载电脑要把上下板分开。

[返回安装目录](#install-list)
## 安装完成效果图

安装完成效果图

**操作流程：** 待补充。

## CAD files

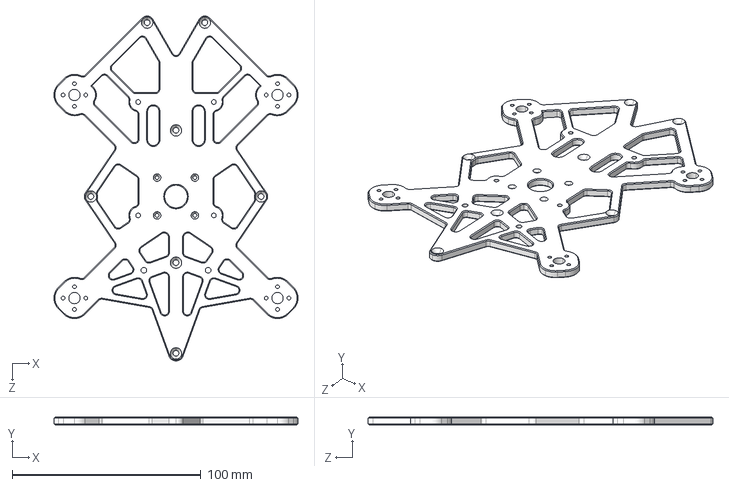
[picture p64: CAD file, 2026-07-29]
3d打印和碳板图/carbon_main_frame.STEP
129.1 x 4.00 x 182.5 mm

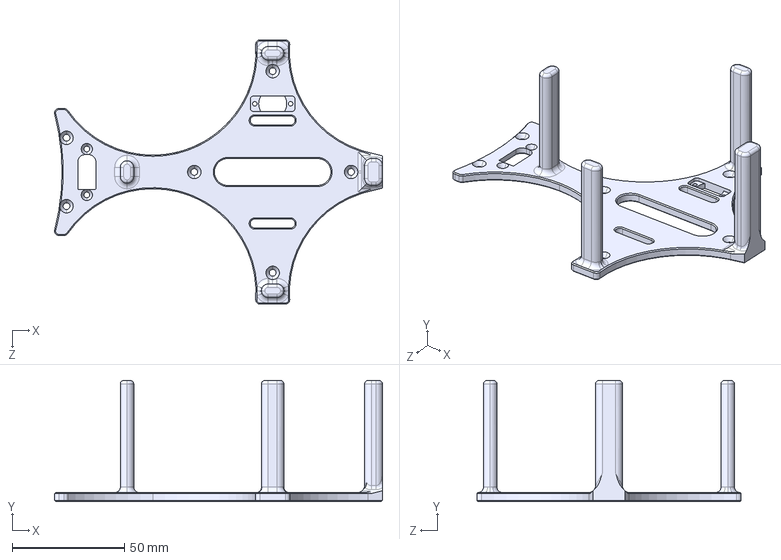
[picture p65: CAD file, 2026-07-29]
3d打印和碳板图/3d_print_bottom_plate.STEP
146.4 x 54.0 x 118.0 mm

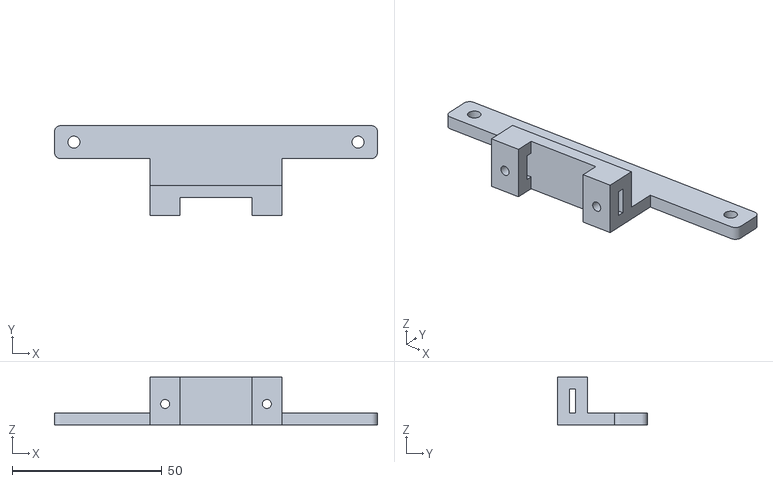
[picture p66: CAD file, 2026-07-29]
3d打印和碳板图/camera_mount (0-degree).STL
108.0 x 30.0 x 16.0

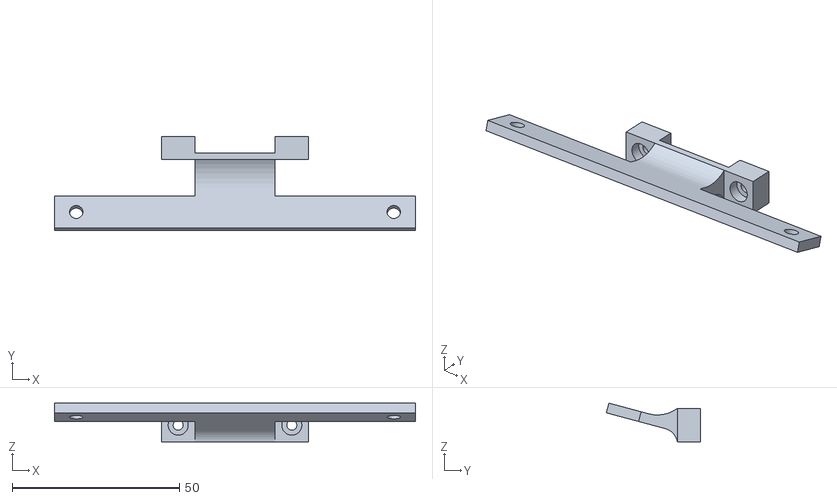
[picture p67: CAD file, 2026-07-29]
3d打印和碳板图/camera_mount (15-degree).STL
108.0 x 28.3 x 11.6

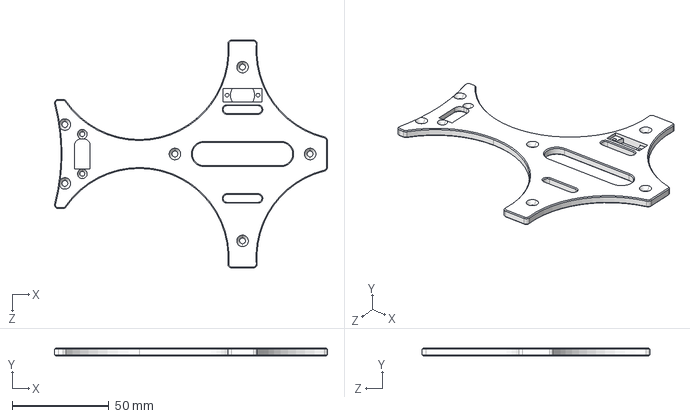
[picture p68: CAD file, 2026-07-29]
3d打印和碳板图/carbon_bottom_plate.STEP
141.4 x 4.00 x 118.0 mm

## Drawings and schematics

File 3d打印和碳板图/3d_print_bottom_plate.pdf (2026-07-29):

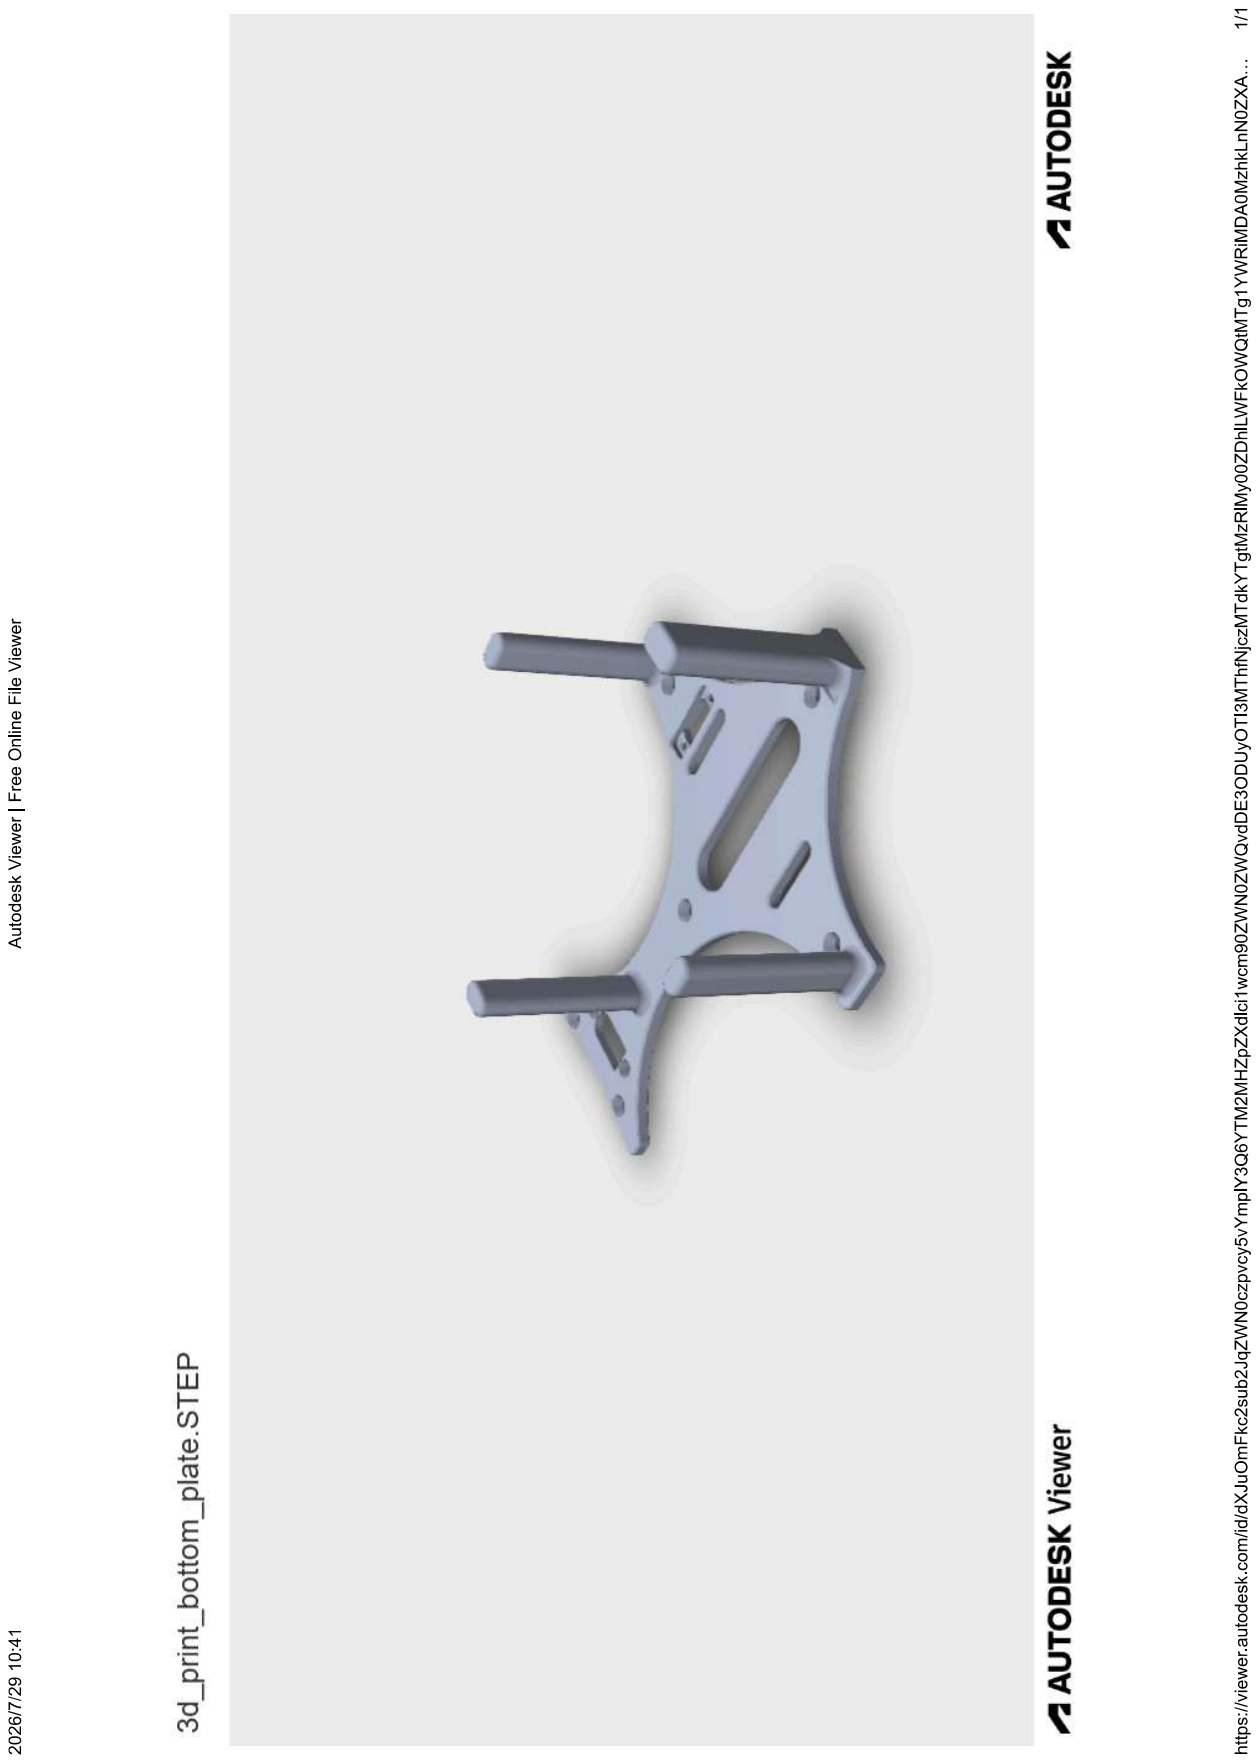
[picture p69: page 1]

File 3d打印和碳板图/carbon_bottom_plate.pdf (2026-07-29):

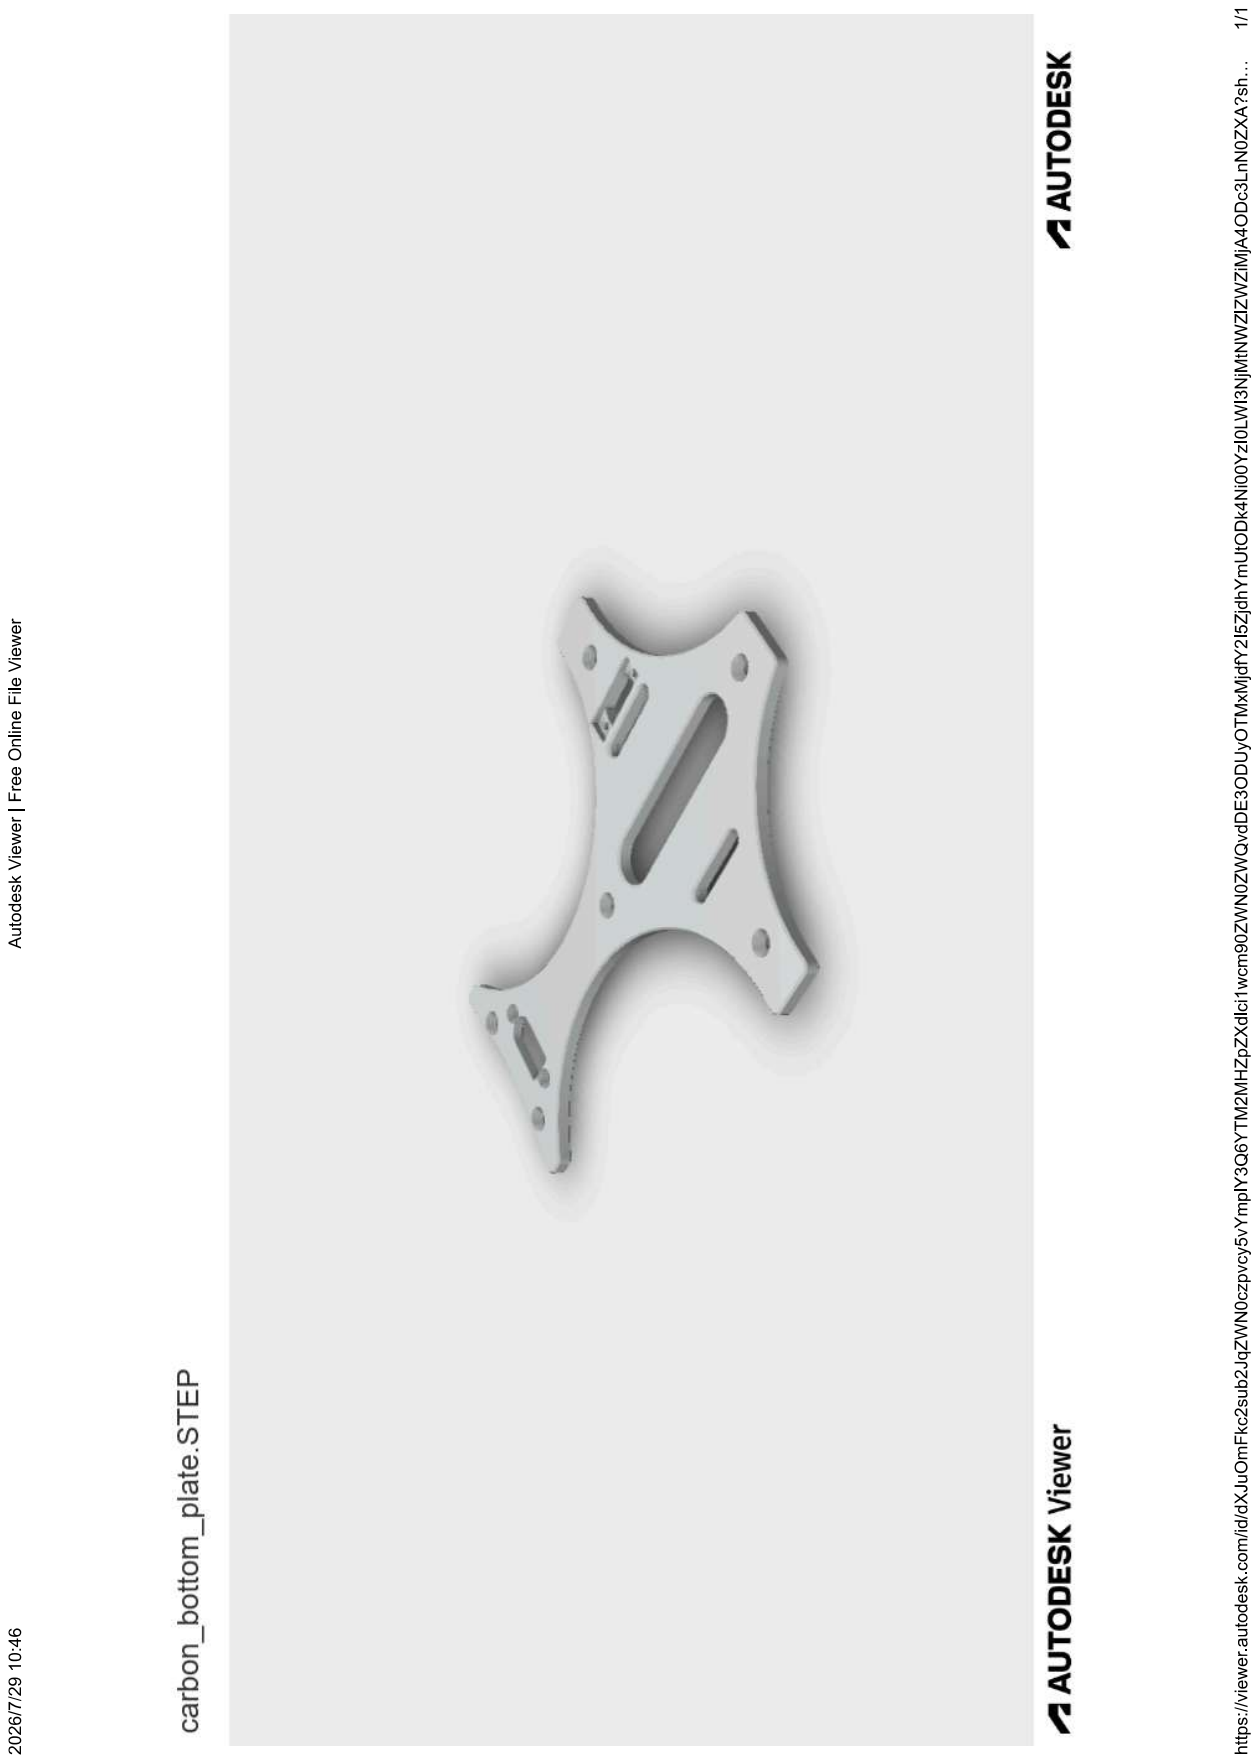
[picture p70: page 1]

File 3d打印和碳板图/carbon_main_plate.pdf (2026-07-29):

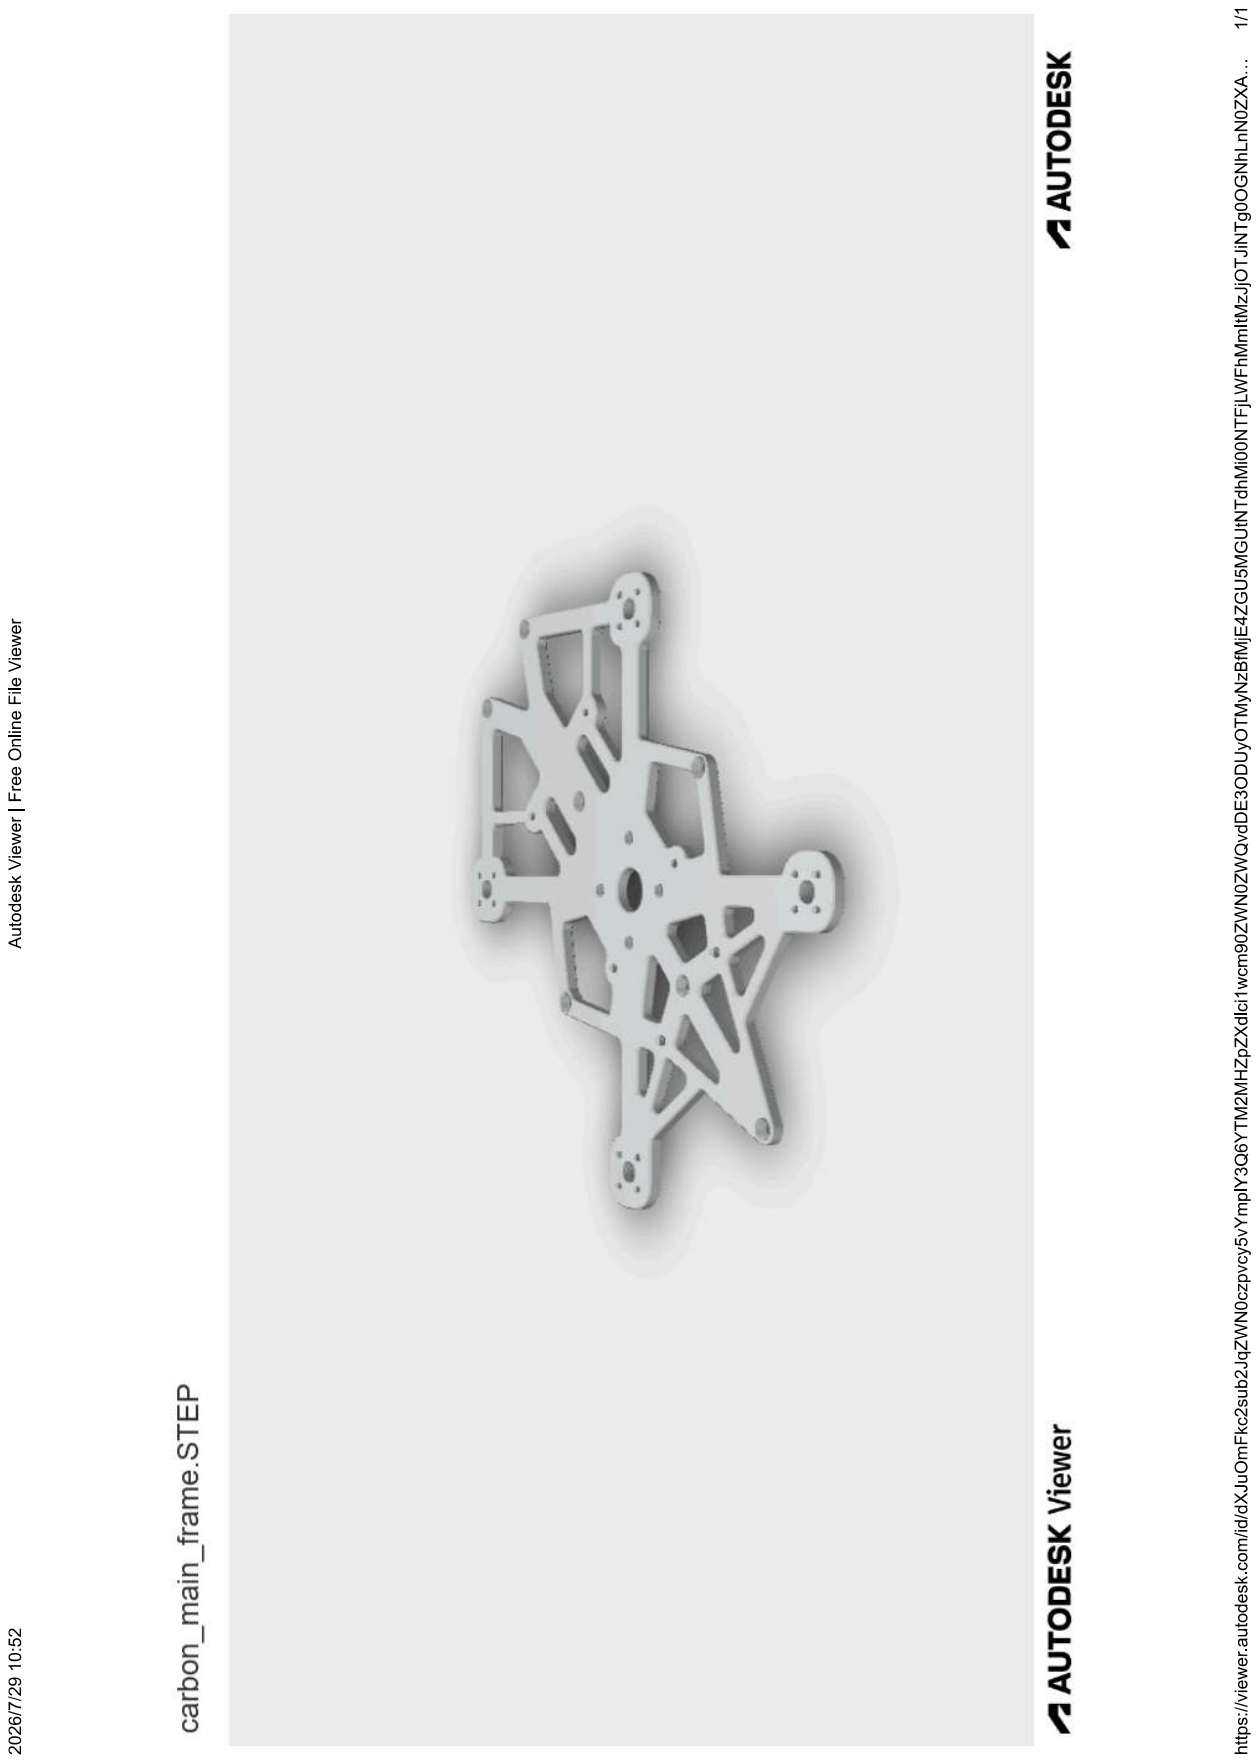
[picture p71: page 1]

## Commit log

2026-07-28 Update installation materials
2026-07-29 Organize 3D print and carbon plate files
    [3d_print_bottom_plate.STEP, camera_mount (0-degree).STL, camera_mount (15-degree).STL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]
